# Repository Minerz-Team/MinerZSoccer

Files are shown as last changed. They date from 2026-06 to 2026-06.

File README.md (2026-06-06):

# ⚽ MinerZ Soccer Robot

An open-source ESP32-based educational soccer robot platform designed for robotics clubs, STEM programs, classroom competitions, and hobbyist projects.

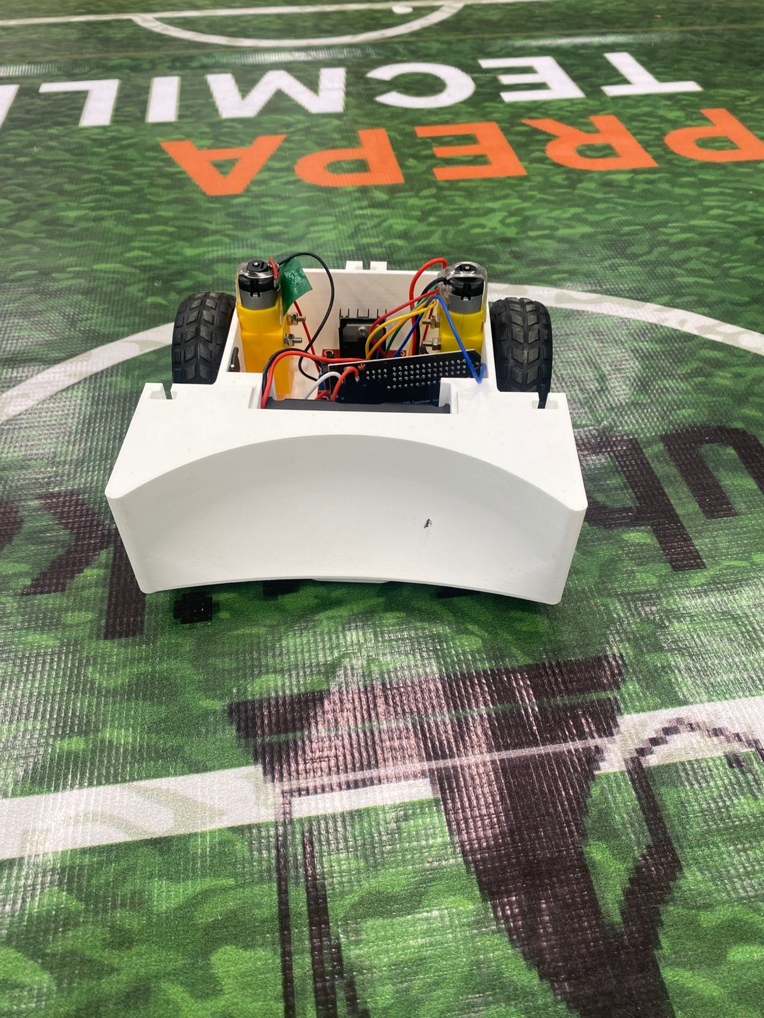
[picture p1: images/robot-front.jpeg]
MinerZ Soccer Robot


---

## Overview

The MinerZ Soccer Robot is a low-cost WiFi-controlled educational robot built around the ESP32 platform.

The project includes:

- ESP32 firmware based on ESP-IDF
- Desktop Driver Station for Windows and macOS
- 3D printable chassis
- Simple modular electronics
- Assembly and wiring documentation
- Optional competition scoring system

The entire platform is designed to be affordable, easy to assemble, and suitable for educational robotics environments.

---

## Features

- ESP32-based control system
- WiFi communication
- Differential drive (tank steering)
- Driver Station support
- Automatic fail-safe protection
- Modular hardware design
- Single-piece 3D printed chassis
- No custom PCB required
- Open-source firmware and documentation

---

## Hardware Overview

Top View

Main hardware components:

- ESP32 DevKit (30-pin)
- ESP32 IO Shield
- L298N Motor Driver
- 2 × TT Gear Motors
- 2 × 48 mm Wheels
- 2 × 18650 Li-Ion Cells
- 2S Battery Holder
- Power Switch
- 3D Printed Chassis

Complete hardware details:

- [Bill of Materials](docs/bom.md)

---

## Assembly

The robot can be assembled using basic tools and commonly available components.

Assembly documentation:

- [Assembly Guide](docs/assembly.md)

Assembly process images:

- Motor installation
- Electronics installation
- Final assembly

---

## Wiring

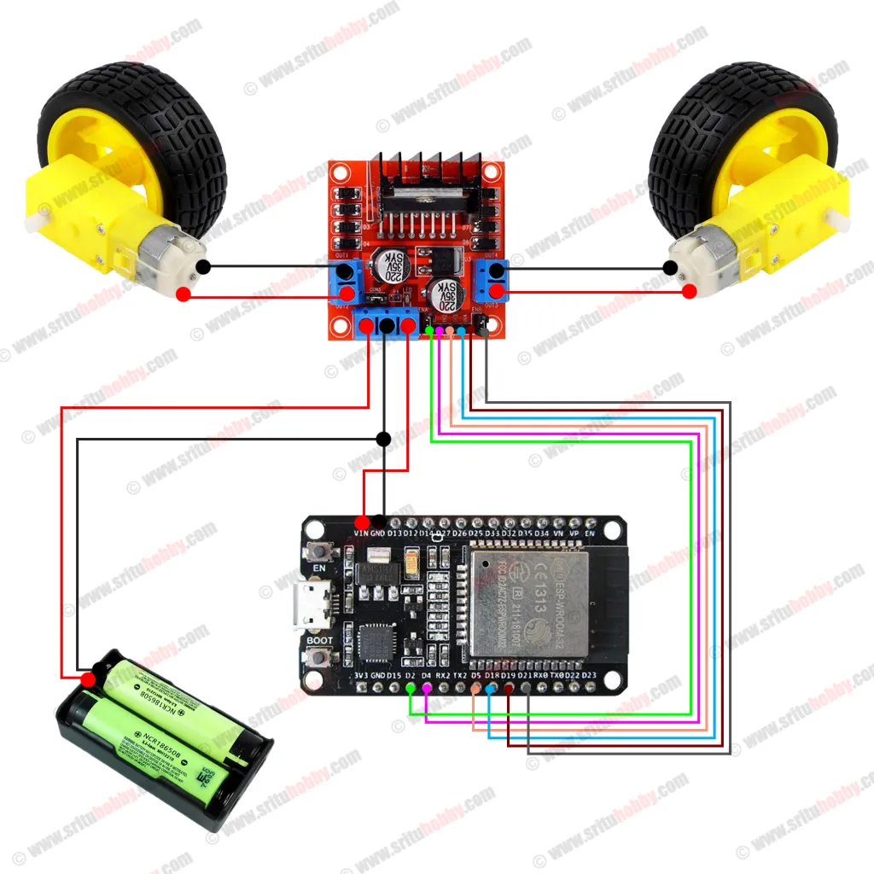
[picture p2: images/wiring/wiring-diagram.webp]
Wiring Overview


The electronics are intentionally simple and use commonly available modules.

Documentation:

- [Wiring Guide](docs/wiring.md)

---

## Software

### ESP32 Firmware

Firmware written in C using ESP-IDF.

Repository:
[MinerZ Soccer Robot Firmware (ESP32)](https://github.com/Minerz-Team/soccer-robot-firmware-esp32.git)

### Driver Station

Desktop application used to control the robot over WiFi.

Supported platforms:

- Windows
- macOS

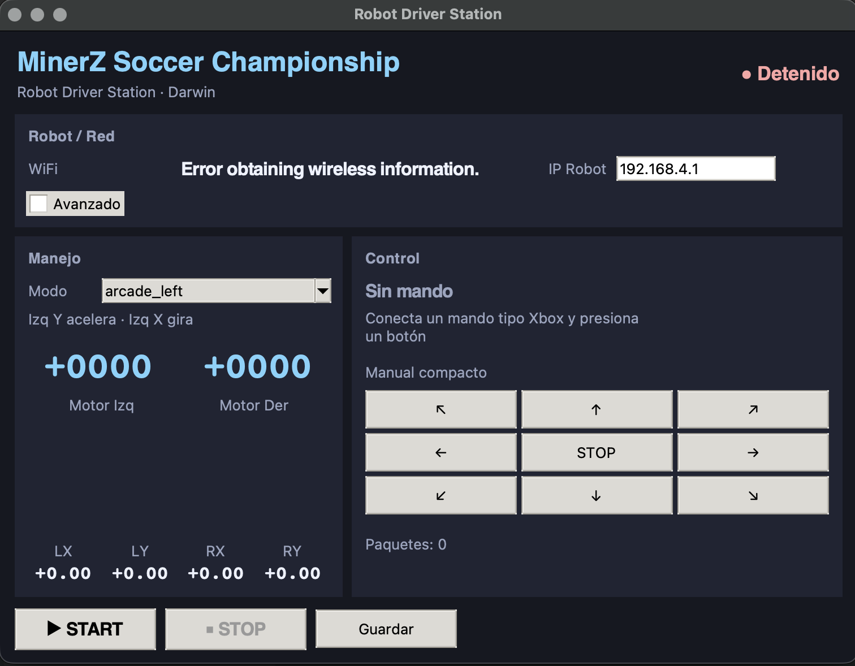
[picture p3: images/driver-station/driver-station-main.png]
Driver Station


Repository:
[MinerZ Soccer Robot Driver Station](https://github.com/Minerz-Team/soccer-robot-driver-station.git)

Precompiled applications will be available through GitHub Releases.

### Scoring System

Competition scoring software inspired by educational robotics competitions.

Repository:

```text
Coming soon
```

---

## Documentation

Available documentation:

- [Bill of Materials](docs/bom.md)
- [Assembly Guide](docs/assembly.md)
- [Wiring Guide](docs/wiring.md)
- [3D Model Attribution](docs/attribution.md)
- [Changelog](CHANGELOG.md)

---

## 3D Model Attribution

The chassis used in this project is based on:

## Soccer Robot – Battle & Soccer Hybrid Chassis

Author:

Diego Armaker

Original model:

[Thingiverse: Soccer Robot – Battle & Soccer Hybrid Chassis](https://www.thingiverse.com/thing:7239226)

License:

Creative Commons Attribution (CC BY)

See:

- [Attribution Details](docs/attribution.md)

---

## Intended Use

This project is intended for:

- Robotics clubs
- STEM programs
- Educational competitions
- Makerspaces
- Hobby robotics enthusiasts

---

## License

Software components are released under the MIT License.

See:

- [LICENSE](LICENSE)

The modified chassis design remains subject to the attribution requirements of the original CC BY license.

---

## Contributing

Contributions, bug reports, documentation improvements, and feature suggestions are welcome.

If you build a robot using this project, feel free to share your results with the community.

---

## Acknowledgments

Special thanks to:

- Espressif Systems
- The open-source robotics community
- Diego Armaker for the original chassis design
- Educators and students supporting robotics initiatives

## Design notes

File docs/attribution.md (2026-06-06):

# Attribution

The MinerZ Soccer Robot chassis is based on a publicly available design published on Thingiverse.

## Original Design

### Soccer Robot – Battle & Soccer Hybrid Chassis

Author:

Diego Armaker

Original publication:

[https://www.thingiverse.com/thing:7239226](https://www.thingiverse.com/thing:7239226)

License:

Creative Commons Attribution (CC BY)

---

## Modifications

The version included in this project has been modified to support:

- ESP32-based control electronics
- L298N motor driver integration
- Battery holder integration
- Educational robotics applications
- Simplified assembly process

---

## License Compliance

This repository provides attribution to the original author as required by the Creative Commons Attribution (CC BY) license.

All credit for the original chassis design belongs to Diego Armaker.

Please refer to the original Thingiverse page for the unmodified design.

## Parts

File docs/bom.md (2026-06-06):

# Bill of Materials (BOM)

This document lists the components required to build the MinerZ Soccer Robot.

## Required Components

| Qty | Component | Notes |
| --- | --- | --- |
| 1 | ESP32 DevKit (30-pin) | Standard ESP32 development board |
| 1 | ESP32 IO Shield | Includes onboard voltage regulator |
| 1 | L298N Motor Driver | Standard dual H-bridge module |
| 2 | TT DC Gear Motors | Typical yellow plastic gear motors, 3–6V |
| 2 | Wheels (48 mm) | Compatible with TT gear motors |
| 1 | 2x18650 Battery Holder | Series configuration (2S) |
| 2 | 18650 Rechargeable Cells | Matched cells recommended |
| 1 | Power Switch | SPST switch |
| 1 | 3D Printed Chassis | See hardware/3d-models |
| 4 | M3x35 Screws | Motor mounting |
| 4 | M3 Nuts | Motor mounting |
| Assorted | Jumper Wires | Male-to-male and male-to-female |

---

## Motor Options

The robot was designed around the common TT-style plastic gear motors.

Typical gear ratios:

- 48:1
- 60:1

Both variants are compatible with the chassis and firmware.

---

## Battery Requirements

The robot uses:

- 2 × 18650 Li-Ion cells
- Connected in series (2S)

Electrical characteristics:

| Parameter | Value |
| --- | --- |
| Nominal Voltage | 7.4 V |
| Fully Charged Voltage | 8.4 V |

Use only quality rechargeable cells in good condition.

---

## Tools Required

Recommended tools:

- Small Phillips screwdriver
- M3 wrench or pliers
- Wire cutter
- Hot glue gun (optional)
- Double-sided foam tape (optional)

---

## Optional Components

These items are not required but may improve reliability:

| Component | Purpose |
| --- | --- |
| Plastic standoffs | Alternative electronics mounting |
| Heat shrink tubing | Cable management |
| Zip ties | Cable management |
| XT30 connector | Battery quick-disconnect |

---

## Electronics Mounting

The design intentionally avoids complicated mounting hardware.

The ESP32 IO Shield and L298N can be secured using:

- Double-sided foam tape
- Hot glue
- Plastic standoffs (optional)

The battery holder slides directly into the dedicated slot integrated into the chassis.

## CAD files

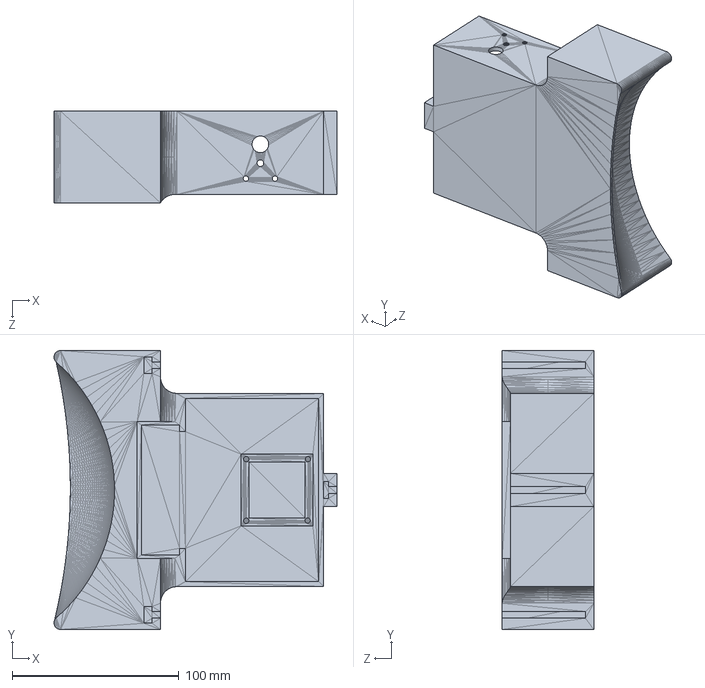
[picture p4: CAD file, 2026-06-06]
hardware/3d-models/Soccer_Robot_v3.SLDPRT
169.9 x 167.6 x 55.0 mm

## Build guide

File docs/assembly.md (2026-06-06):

# Assembly Guide

This guide describes the recommended assembly process for the MinerZ Soccer Robot.

---

## Before You Start

Verify that all components listed in the BOM are available.

---

## Step 1 – Install the Motors

Insert the two TT gear motors into the motor mounts integrated into the chassis.

Secure each motor using:

- 2 × M3x35 screws
- 2 × M3 nuts

Total hardware required:

- 4 × M3x35 screws
- 4 × M3 nuts

Verify that both motors are firmly secured.

Motors installed

---

## Step 2 – Connect the Motor Wires

Connect the motor terminals to the L298N motor driver.

At this stage the motor polarity is not critical because motor direction can be adjusted later through wiring or firmware configuration.

Recommended wire colors:

- Red = Motor positive
- Black = Motor negative

---

## Step 3 – Connect Control Wires

Connect jumper wires between the ESP32 IO Shield and the L298N.

Do not connect the ESP32 board yet.

Refer to the wiring guide:

- [Wiring Guide](docs/wiring.md)

---

## Step 4 – Install the Battery Holder

Slide the 2x18650 battery holder into the dedicated slot integrated into the chassis.

No additional hardware should be required.

Verify that the holder cannot move during operation.

---

## Step 5 – Connect Power Wiring

Wire the battery holder, switch, ESP32 shield, and L298N according to the wiring guide.

The positive battery lead must pass through the power switch before reaching the electronics.

Wiring the battery

---

## Step 6 – Mount Electronics

Mount the following modules:

- ESP32 IO Shield
- L298N Motor Driver

Recommended methods:

- Double-sided foam tape
- Hot glue

Optional:

- Plastic standoffs

Electronics mounted

---

## Step 7 – Verify Connections

Before inserting the ESP32:

Verify:

- Battery polarity
- L298N power connections
- Shield power connections
- Shared ground connections
- Motor wiring

Carefully inspect all wiring.

Incorrect polarity may permanently damage electronic components.

---

## Step 8 – Install the ESP32

Insert the ESP32 into the IO Shield.

Make sure all pins are properly aligned before applying pressure.

---

## Step 9 – Program the ESP32

Flash the firmware before final deployment.

Programming is significantly easier before the USB port becomes difficult to access.

Firmware repository:
[soccer-robot-firmware-esp32](https://github.com/Minerz-Team/soccer-robot-firmware-esp32.git)

---

## Step 10 – First Power-On Test

Turn the robot on.

Verify:

- ESP32 powers correctly
- WiFi network becomes available
- Motors remain stopped at startup
- No excessive heating is observed

If everything works correctly, proceed with Driver Station testing.

---

## Driver Station Test

Connect the Driver Station to the robot and verify:

- Forward movement
- Reverse movement
- Left turn
- Right turn

If a motor rotates in the wrong direction, swap the motor wires or adjust the firmware motor inversion settings.

---

## Assembly Complete

The robot is now ready for operation.

Completed assembly

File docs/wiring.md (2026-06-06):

# Wiring Guide

This document describes the recommended wiring configuration for the MinerZ Soccer Robot.

---

## System Overview

The robot consists of:

- ESP32 DevKit (30-pin)
- ESP32 IO Shield
- L298N Motor Driver
- Two TT Gear Motors
- 2S Battery Pack (2x18650)
- Power Switch

---

## Power Distribution

The robot uses a 2S battery pack.

Electrical characteristics:

| Parameter | Value |
| --- | --- |
| Nominal Voltage | 7.4 V |
| Fully Charged Voltage | 8.4 V |

The positive battery lead is routed through the power switch before reaching the electronics.

### Power Topology

```text
Battery (+)
    │
    ▼
Power Switch
    │
    ├────────► ESP32 IO Shield VIN
    │
    └────────► L298N VIN

Battery (-)
    │
    ├────────► ESP32 IO Shield GND
    │
    └────────► L298N GND
```

All grounds must be connected together.

---

## Control Connections

The firmware expects the following pin assignment.

### ESP32 → L298N

| ESP32 GPIO | L298N Pin | Function |
| --- | --- | --- |
| GPIO32 | ENA | Motor A PWM |
| GPIO33 | IN1 | Motor A Direction |
| GPIO25 | IN2 | Motor A Direction |
| GPIO26 | ENB | Motor B PWM |
| GPIO18 | IN3 | Motor B Direction |
| GPIO27 | IN4 | Motor B Direction |

These are the default firmware pin assignments.

Changing them requires modifying the firmware configuration.

---

## Motor Connections

### Motor A

```text
L298N OUT1
L298N OUT2
```

Connect to the left motor.

### Motor B

```text
L298N OUT3
L298N OUT4
```

Connect to the right motor.

If a motor rotates in the wrong direction:

- Swap the motor wires
- Or enable the motor inversion option in firmware

---

## Recommended Wiring Diagram

Wiring Diagram

---

## Wiring Verification Checklist

Before inserting the batteries:

- [ ] Battery polarity verified
- [ ] Shared ground connected
- [ ] Switch installed on positive lead
- [ ] ESP32 shield powered correctly
- [ ] L298N powered correctly
- [ ] Motor wires connected
- [ ] No exposed conductors touching

---

## First Power-On

Expected behavior:

1. ESP32 powers on.
2. WiFi network becomes available.
3. Motors remain stopped.
4. No component overheats.

If anything behaves unexpectedly, disconnect power immediately and recheck wiring.

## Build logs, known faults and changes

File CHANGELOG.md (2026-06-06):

# Changelog

All notable changes to this project will be documented in this file.

---

## v1.0.0

Initial public release.

### Included

- ESP32 firmware support
- WiFi robot control
- UDP communication protocol
- Driver Station support
- 3D printable chassis
- Assembly documentation
- Wiring documentation
- BOM documentation

### Hardware

- ESP32 DevKit
- ESP32 IO Shield
- L298N Motor Driver
- TT Gear Motors
- 2S Li-Ion Battery System

### Documentation

- README
- BOM
- Assembly Guide
- Wiring Guide
- Attribution Information

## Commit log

2026-06-05 Revise README.md with comprehensive project details
    Expanded README to provide detailed project information, including features, hardware components, assembly instructions, software components, and intended use.
2026-06-06 Add CAD File
    [Soccer_Robot_v3.SLDPRT]
